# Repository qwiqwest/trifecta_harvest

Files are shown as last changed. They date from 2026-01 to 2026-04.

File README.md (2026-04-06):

# Smart Harvest

### Solar-Powered Edge Computer Vision System for Automated Fruit Ripeness Monitoring

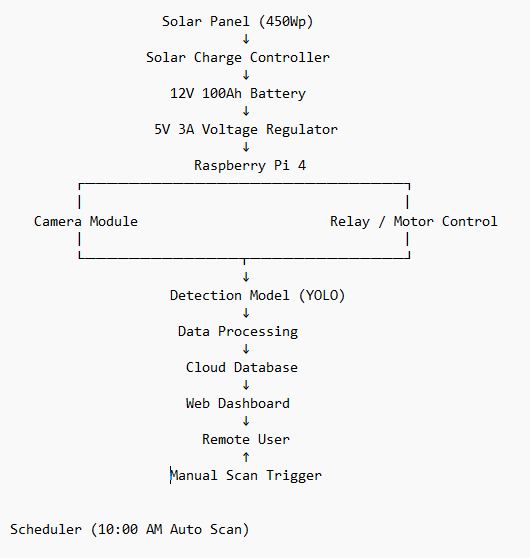
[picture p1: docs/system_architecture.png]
System Architecture


Smart Harvest is an embedded edge-AI system developed to support automated fruit ripeness monitoring in agricultural environments. The system integrates renewable energy, embedded computing, computer vision, and cloud-based monitoring to enable autonomous field operation.

The platform performs scheduled image acquisition and ripeness detection using a YOLO-based model deployed on a Raspberry Pi. Detection results are transmitted to a cloud database and visualized through a web-based monitoring dashboard, allowing remote observation and manual system triggering.

---

## System Architecture

The system consists of three main subsystems:

**Power System**

* 450 Wp solar panel
* Solar charge controller
* 12V 100Ah battery
* 5V 3A voltage regulator

**Edge Processing**

* Raspberry Pi 4 as the main controller
* Camera module for image acquisition
* YOLO-based ripeness detection model
* Custom relay PCB for motor control
* Automated daily scanning scheduler (10:00 AM)

**Cloud Monitoring**

* Cloud database for data storage
* Web-based IoT dashboard
* Remote user monitoring and manual scan triggering

---

## Key Capabilities

* Solar-powered autonomous operation
* Edge AI deployment for on-device fruit detection
* Integrated mechanical scanning mechanism
* Remote monitoring and control through web interface
* Full hardware–software system integration

---

## Demonstration

Live demonstration:
https://youtu.be/be947bb0I0M

Live system interface:
https://smartharvest.online
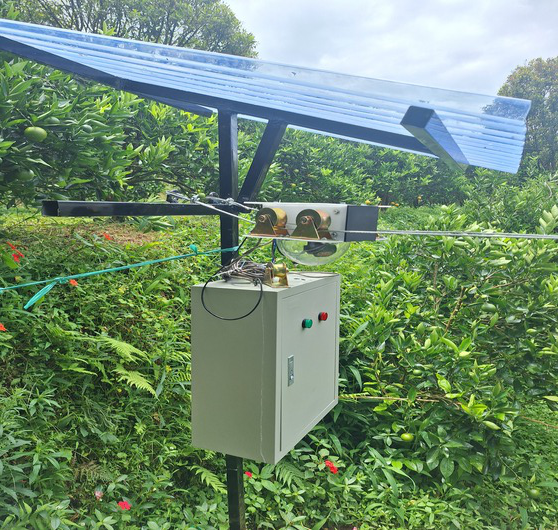
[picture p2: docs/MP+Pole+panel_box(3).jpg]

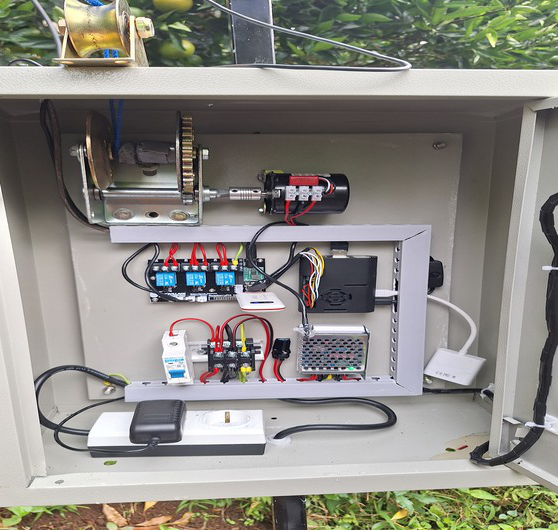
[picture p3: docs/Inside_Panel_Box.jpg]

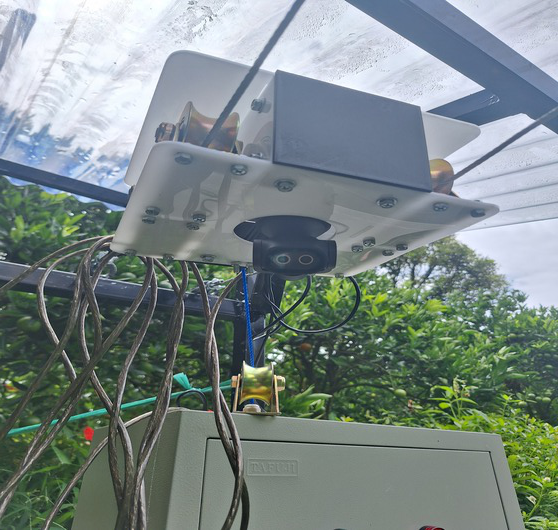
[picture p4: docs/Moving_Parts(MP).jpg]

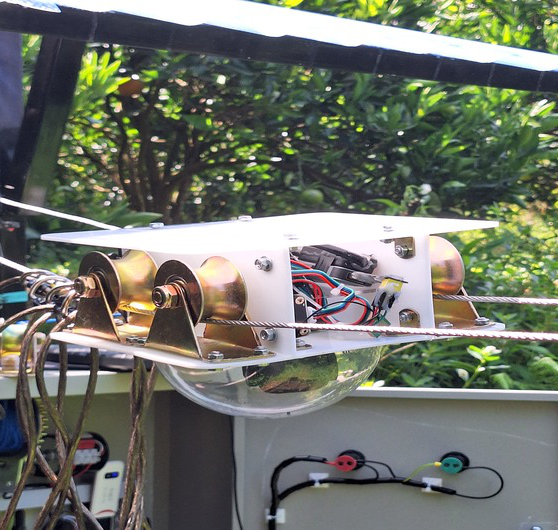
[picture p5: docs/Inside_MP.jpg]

---

## Repository Structure

* docs/ – system documentation and architecture diagram
* hardware/ – electrical design, PCB files, and wiring
* software/ – detection model, system control scripts, and dashboard code

---

## Technologies

Python • Raspberry Pi • YOLO • PCB Design • Solar Energy System • Web Dashboard • Cloud Database

---

## Future Research Direction

This project represents an initial step toward developing autonomous, solar-powered agricultural support systems.

Future work includes the development of a solar-powered automated organic waste composting system designed to convert agricultural waste into sustainable fertilizer through controlled mechanical processing and embedded control logic.

The focus will be on low-energy operation, system reliability, and sustainable off-grid deployment.

**Author**

Muhammad Rafli Abdillah
Undergraduate Student – Electrical Engineering
Research Interests: Embedded Systems, Computer Vision, Precision Agriculture

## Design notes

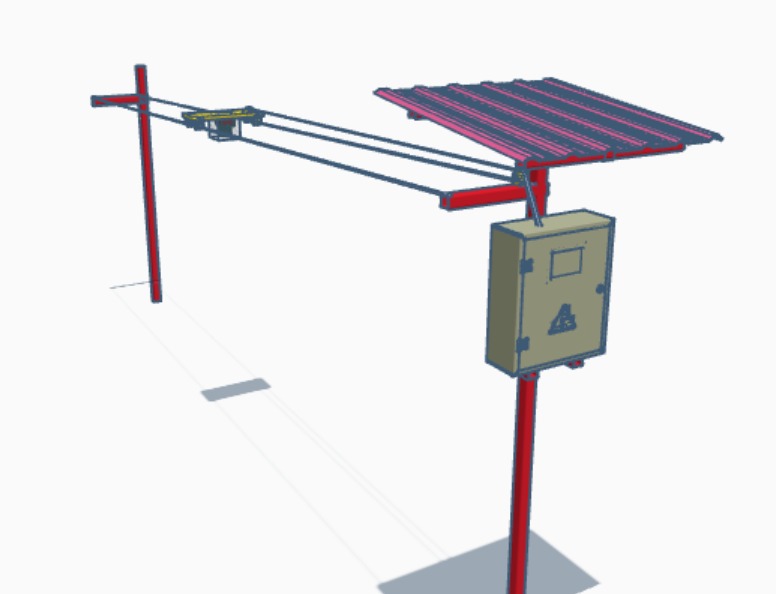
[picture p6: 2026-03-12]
hardware/mechanical/pole_design/mechanicalPole_desain_1.jpeg

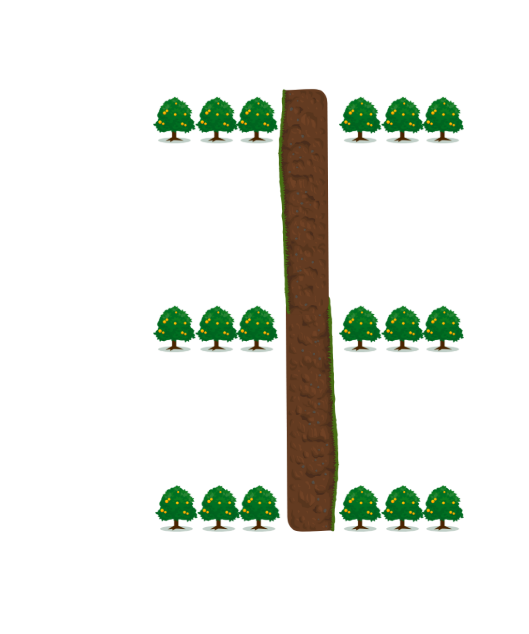
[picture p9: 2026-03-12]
software/dashboard/iot_dashboard/assets/img/peta5.png

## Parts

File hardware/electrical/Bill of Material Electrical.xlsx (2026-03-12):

No | Item |  | Qty
1 | Raspberry Pi 4 4GB |  | 1
2 | EMEET 4K PTZ |  | 1
3 | USB Extender |  | 1
4 | Pilot Lamp |  | 2
5 | AC 220V Motor |  | 1
6 | 4G Modem |  | 1
7 | MCB AC C2 |  | 1
8 | PSU Switching 12V 5A |  | 1
9 | Terminal 2 Stopkontak |  | 1
10 | Steker Arder Waterproof |  | 1
11 | Terminal Block Double DIN Rail |  | 3
12 | PSU Adapter Raspberry Pi 4 5V 3A USB Type C |  | 1
13 | Jack Power 12V |  | 2
14 | Relay Control Board | Relay 12V | 3
 |  | PC817 Optocoupler | 3
 |  | S8050 Transistor | 3
 |  | Stepdown MP1584 | 1
 |  | Dioda 1N4148 | 3
 |  | Resistor 220 | 6
 |  | Resistor 10k | 2
 |  | Konektor FP 40P | 1
 |  | Soket 12V PCB | 1
 |  | JST XH2.54 2P | 2
 |  | JST XH2.54 4P | 2
 |  | USB Socket | 2
 |  | Terminal Block 3P | 3

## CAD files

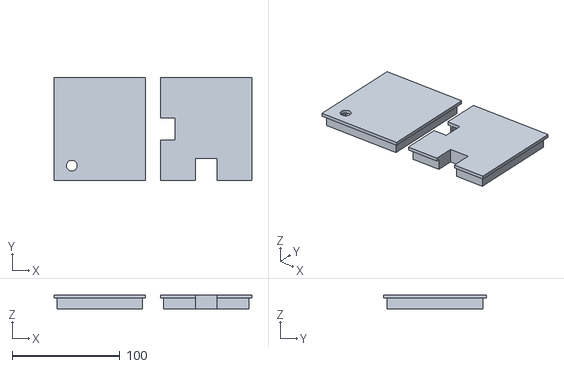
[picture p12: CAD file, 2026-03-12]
hardware/mechanical/moving_parts_design/penutupMovingPart.stl
183.5 x 95.0 x 13.0

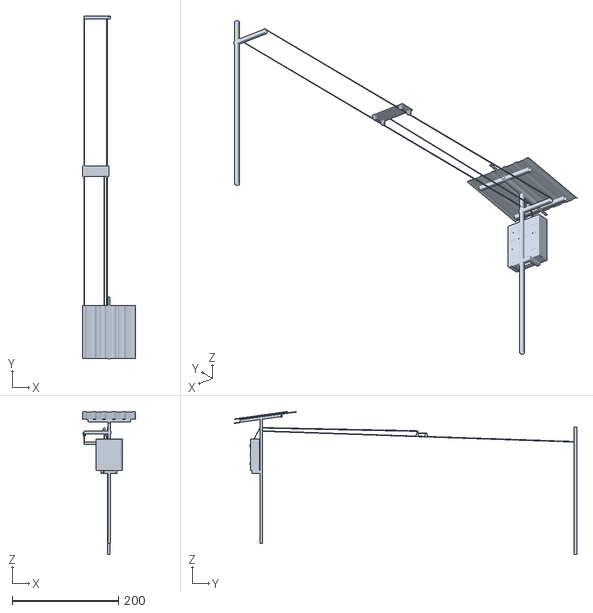
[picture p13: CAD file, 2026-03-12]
hardware/mechanical/pole_design/mechanicalPole_desain_1.stl
100.4 x 645.8 x 269.5

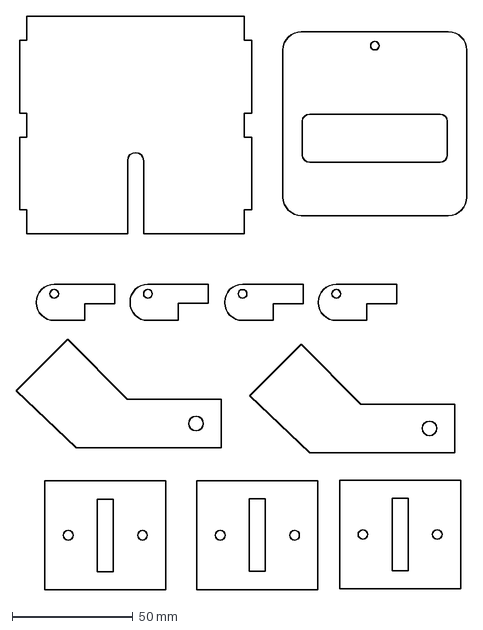
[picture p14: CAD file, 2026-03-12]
hardware/mechanical/moving_parts_design/middle.DXF
186.3 x 237.1 mm

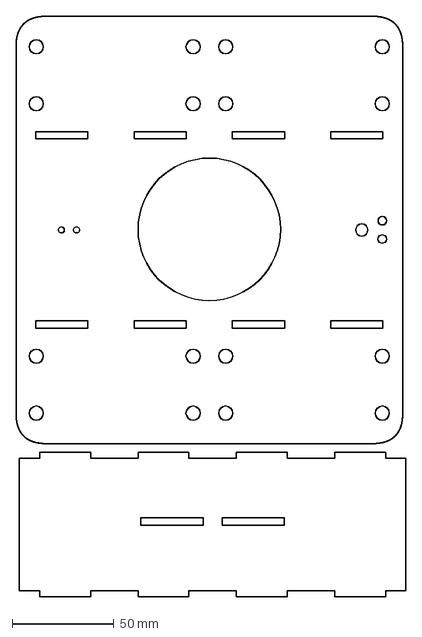
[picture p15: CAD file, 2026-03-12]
hardware/mechanical/moving_parts_design/bottom+left.DXF
191.6 x 285.2 mm

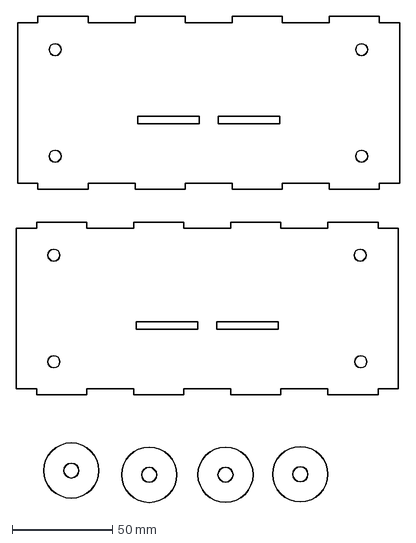
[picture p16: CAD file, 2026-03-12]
hardware/mechanical/moving_parts_design/rev1.DXF
190.7 x 241.9 mm

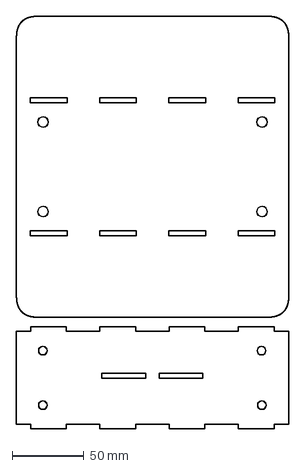
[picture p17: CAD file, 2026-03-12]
hardware/mechanical/moving_parts_design/top+right.DXF
190.2 x 287.8 mm

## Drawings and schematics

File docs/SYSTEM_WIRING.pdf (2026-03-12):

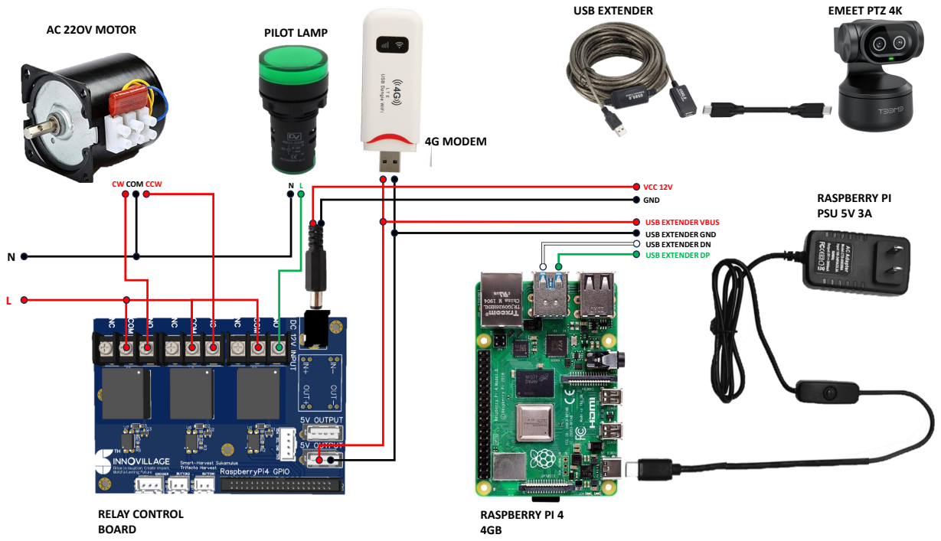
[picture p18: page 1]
CW COM CCW; VCC 12V GND; USB EXTENDER; EMEET PTZ 4K; AC 22OV MOTOR; PILOT LAMP; 4G MODEM; RASPBERRY PI 4 4GB; RELAY CONTROL BOARD; RASPBERRY PI PSU 5V 3A

USB EXTENDER VBUS
USB EXTENDER GND
USB EXTENDER DN
USB EXTENDER DP

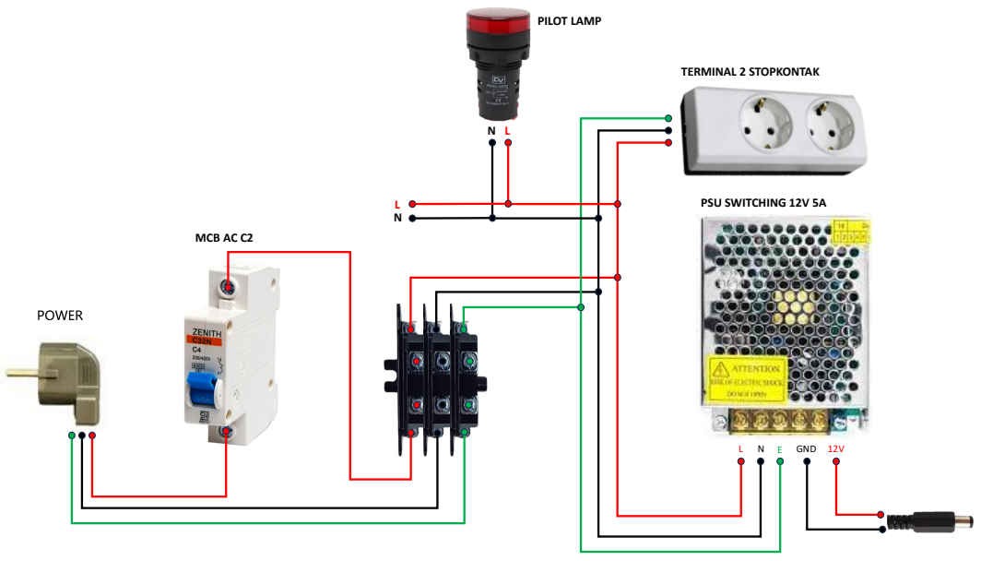
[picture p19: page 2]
GND 12V; MCB AC C2; PILOT LAMP; TERMINAL 2 STOPKONTAK; PSU SWITCHING 12V 5A

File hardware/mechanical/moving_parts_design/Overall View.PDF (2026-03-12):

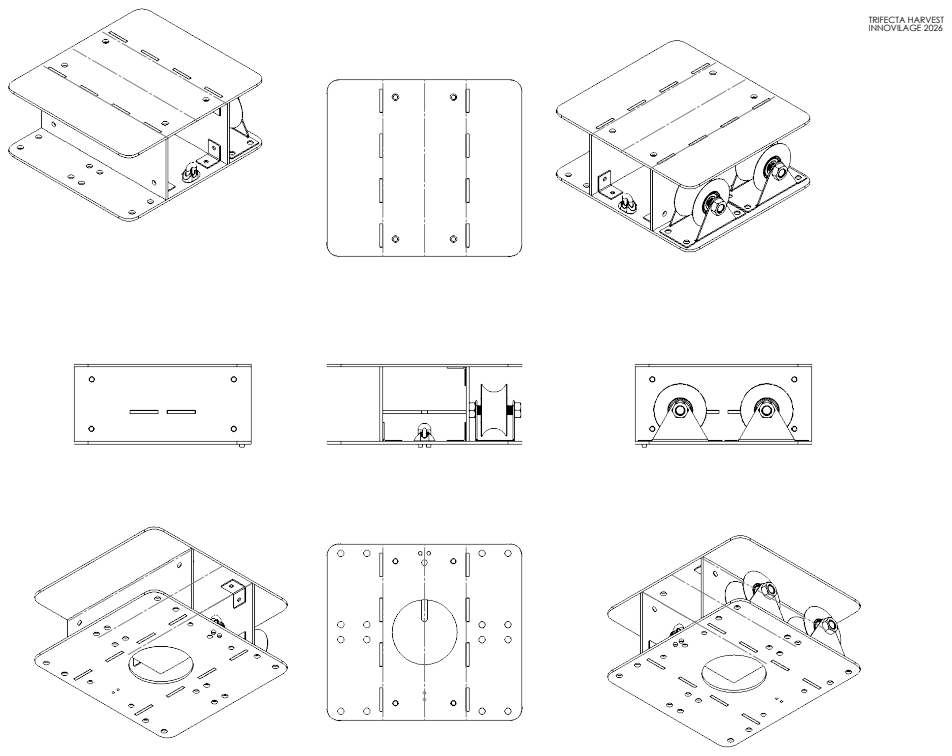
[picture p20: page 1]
TRIFECTA HARVEST INNOVILAGE 2026

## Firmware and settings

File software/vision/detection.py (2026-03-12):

import time
import requests
import subprocess
import RPi.GPIO as GPIO
from ultralytics import YOLO
import cv2


JUMLAH_BARIS = 2
MAX_RETRY = 1  # supaya tidak infinite loop

#Definisi pin
#17 -> lampu
#22 -> tarik
#27 -> ulur

MOTOR_GPIO_ACTIVE = True

# Gunakan penomoran BCM
GPIO.setmode(GPIO.BCM)

# Daftar pin
pinLampu = 17
pinTarik = 22
pinUlur = 27
pinMagnet = 26
pinStopper = 20
pins = [pinLampu, pinTarik, pinUlur, pinMagnet, pinStopper]

a1 = 0
a2 = 0
b1 = 0
b2 = 0

payload = {
    "a1":a1,
    "a2":a2,
    "b1":b1,
    "b2":b2
}

url = "https://smartharvest.online/assets/php/api_insert.php"

model = YOLO(r"/home/ubuntu2025/Desktop/yolov8/best.pt")

headers = {
    "User-Agent": "Mozilla/5.0",
    "Accept": "*/*"
}

#===FUNCTION===
def deteksi_jeruk(path, filename):
    result = model(path +filename +".jpg")
    result[0].save(filename= path + filename +"_dtc.jpg")
    jumlah_matang = 0
    jumlah_mentah = 0

    for box in result[0].boxes:
        cid = int(box.cls)

        if cid == 0:
            jumlah_matang += 1
        elif cid == 1:
            jumlah_mentah += 1

    return jumlah_mentah, jumlah_matang

def kirim_ke_database():
    payload = {
        "a1":a1,
        "a2":a2,
        "b1":b1,
        "b2":b2
    }
    print(payload)
    r = requests.post(
    url,
    data=payload,
    headers=headers,
    timeout=15,
    allow_redirects=True
    )
    print(r.status_code)
    print(r.text)
    
def bacaStopper():
    state = GPIO.input(pinStopper)
    print(state)
    return state

def setupGPIO():
    GPIO.setmode(GPIO.BCM)
    GPIO.setup(pins, GPIO.OUT)
    GPIO.setup(pinLampu, GPIO.OUT)
    GPIO.setup(pinMagnet, GPIO.IN)
    GPIO.setup(pinStopper, GPIO.IN)

def tarik(onDelay):
    
    GPIO.output(pinLampu, GPIO.HIGH)
    GPIO.output(pinTarik, GPIO.HIGH)
    print("tarik on")
    time.sleep(onDelay)
                
    GPIO.output(pinTarik, GPIO.LOW)
    print("tarik off")
    
    GPIO.output(pinLampu, GPIO.LOW)
            
        
    
def ulur(onDelay, offDelay):
    GPIO.output(pinLampu, GPIO.HIGH)
    if MOTOR_GPIO_ACTIVE:
        GPIO.output(pinUlur, GPIO.HIGH)
        print("ulur on")
    time.sleep(onDelay)
    
    if MOTOR_GPIO_ACTIVE:
        GPIO.output(pinUlur, GPIO.LOW)
        print("ulur off")
    time.sleep(offDelay)
    GPIO.output(pinLampu, GPIO.LOW)
    

def rotateCamera(orientasi):
    #pan_absolute 0x009a0908 (int)      : min=-540000 max=540000 step=3600 default=0 value=0
    #tilt_absolute 0x009a0909 (int)     : min=-324000 max=324000 step=3600 default=0 value=0
    #kiri   :
    #v4l2-ctl --set-ctrl=pan_absolute=-380000
    #v4l2-ctl --set-ctrl=tilt_absolute=50000
    #tengah :
    #v4l2-ctl --set-ctrl=pan_absolute=-80000
    #v4l2-ctl --set-ctrl=tilt_absolute=50000
    if orientasi == "KIRI":
        subprocess.run(["v4l2-ctl", "-d", "/dev/video0", "--set-ctrl=pan_absolute=-324000"])
        subprocess.run(["v4l2-ctl", "-d", "/dev/video0", "--set-ctrl=tilt_absolute=36000"])
    elif orientasi == "KANAN": 
        subprocess.run(["v4l2-ctl", "-d", "/dev/video0", "--set-ctrl=pan_absolute=324000"])
        subprocess.run(["v4l2-ctl", "-d", "/dev/video0", "--set-ctrl=tilt_absolute=36000"])
    elif orientasi == "HOME":
        subprocess.run(["v4l2-ctl", "-d", "/dev/video0", "--set-ctrl=pan_absolute=0"])
        subprocess.run(["v4l2-ctl", "-d", "/dev/video0", "--set-ctrl=tilt_absolute=-270000"])
    elif orientasi == "DEFAULT":
        subprocess.run(["v4l2-ctl", "-d", "/dev/video0", "--set-ctrl=pan_absolute=0"])
        subprocess.run(["v4l2-ctl", "-d", "/dev/video0", "--set-ctrl=tilt_absolute=0"])

def capture_image(path, filenameSave):
    cap = cv2.VideoCapture("/dev/video0", cv2.CAP_V4L2)

    cap.set(cv2.CAP_PROP_FOURCC, cv2.VideoWriter_fourcc(*'MJPG'))
    cap.set(cv2.CAP_PROP_FPS, 15)
    cap.set(cv2.CAP_PROP_FRAME_WIDTH, 3840)
    cap.set(cv2.CAP_PROP_FRAME_HEIGHT, 2160)
    
    for _ in range(120):
        ret, frame = cap.read()
    ret, frame = cap.read()

    if ret:
        frame = cv2.flip(frame, 0)
        cv2.imwrite(path + filenameSave +".jpg", frame)
        print("Gambar tersimpan dengan shape:", frame.shape)
    else:
        print("Gagal membaca kamera!")

    cap.release()



def proses_deteksi(path, baris, sisi, filenameSave):
    global a1, a2, b1, b2
    retry = 0
    mentah = 0
    matang = 0

    # while mentah == 0 and matang == 0:
    #     print("Ambil gambar ulang...")
    capture_image(path, filenameSave)

    mentah, matang = deteksi_jeruk(path, filenameSave)

    print("Mentah:", mentah)
    print("Matang:", matang)

        # retry += 1
        # if retry >= MAX_RETRY:
        #     print("Gagal deteksi setelah beberapa percobaan")
        #     break
    
    totalBuah = matang + mentah
    
    if sisi == "KIRI":
        if baris == 1:
            a1 = matang
            print(f"a1={a1}")
        elif baris == 2:
            a2 = matang
            print(f"a2={a2}")
    elif sisi == "KANAN":
        if baris == 1:
            b1 = matang
            print(f"b1={b1}")
        elif baris == 2:
            b2 = matang
            print(f"b2={b2}")
    
    
    # if sisi == "KIRI":
    #     payload[f"baris{baris}"]["A"]["persentase"] = persentase
    # if sisi == "KANAN":
    #     payload[f"baris{baris}"]["B"]["persentase"] = persentase
    
    return mentah, matang

# ===============================
# MAIN SETUP
# ===============================
if __name__ == "__main__":
        
    path = "/home/ubuntu2025/Desktop/yolov8/img_out/"       
    filename = time.strftime("foto_%Y%m%d_%H%M%S")
    
    setupGPIO()
    rotateCamera("DEFAULT")
    time.sleep(2)
    rotateCamera("HOME")
    time.sleep(2)
    #tarik(5)
    # ===============================
    # MAIN LOOP
    # ===============================

    for baris in range(1, JUMLAH_BARIS+1):
        print(f"Mulai baris {baris}")

        # Geser/ulur mekanik
        if baris == 1:
            rotateCamera("DEFAULT")
            time.sleep(2)
            rotateCamera("HOME")
            ulur(22, 1)
        elif baris == 2:
            rotateCamera("DEFAULT")
            time.sleep(2)
            rotateCamera("HOME")
            ulur(110, 1)#30,1

        # ======================
        # ROTASI KIRI
        # ======================
        rotateCamera("DEFAULT")
        time.sleep(2)
        rotateCamera("KIRI")
        filenameKiri = filename + f"baris{baris}_kiri"
        proses_deteksi(path, baris, "KIRI", filenameKiri)
        
        # ======================
        # ROTASI KANAN
        # ======================
        rotateCamera("DEFAULT")
        time.sleep(2)
        rotateCamera("KANAN")
        filenameKanan = filename + f"baris{baris}_kanan"
        proses_deteksi(path, baris, "KANAN", filenameKanan)
        


    # ===============================
    # Kembali ke HOME
    # ===============================
    kirim_ke_database()
    rotateCamera("DEFAULT")
    time.sleep(2)
    rotateCamera("HOME")
    tarik(137)
    rotateCamera("DEFAULT")
    time.sleep(2)
    rotateCamera("HOME")
    print("Selesai semua baris")

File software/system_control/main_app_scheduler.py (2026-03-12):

from apscheduler.schedulers.background import BackgroundScheduler
import subprocess
import datetime
import threading
import requests
import time
import deteksi

# ========================
# CONFIG WEB COMMAND
# ========================
URL_GET = "https://smartharvest.online/assets/php/get_command.php"
URL_DONE = "https://smartharvest.online/assets/php/done_command.php"

headers = {
    "User-Agent": "Mozilla/5.0",
    "Accept": "*/*"
}

scheduler = BackgroundScheduler()
deteksi_lock = threading.Lock()


# ========================
# FUNGSI KAMERA
# ========================
def set_kamera_home():
    deteksi.rotateCamera("DEFAULT")
    time.sleep(2)
    deteksi.rotateCamera("HOME")
    deteksi.setupGPIO()
    #if deteksi.bacaStopper():
     #   deteksi.tarik(10, 1)


# ========================
# FUNGSI DETEKSI
# ========================
def jalankan_deteksi():
    if deteksi_lock.locked():
        print("Deteksi masih berjalan, skip...")
        return

    with deteksi_lock:
        print("Deteksi dijalankan:", datetime.datetime.now())

        # Gunakan run supaya blocking dan lock benar-benar efektif
        subprocess.run(
            ["/home/ubuntu2025/Desktop/yolov8/venv3.10/bin/python", "/home/ubuntu2025/Desktop/yolov8/source_code/deteksi.py"]
        )

        print("Deteksi selesai")


# ========================
# POLLING WEB MANUAL COMMAND
# ========================
def polling_web_command():
    while True:
        try:
            r = requests.get(URL_GET, headers=headers, timeout=10).json()

            if r.get("command"):
                print("COMMAND dari web:", r)

                if r["command"] == "scan":
                    requests.post(
                        URL_DONE,
                        data={"id": r["id"]},
                        headers=headers,
                        timeout=10
                    )
                    jalankan_deteksi()

                

        except Exception as e:
            print("Error polling:", e)

        time.sleep(10)


# ========================
# INIT SISTEM
# ========================
print("Set kamera ke HOME")
set_kamera_home()

print("Start scheduler 10:00")

# Jadwal otomatis (ubah sesuai kebutuhan)
#scheduler.add_job(jalankan_deteksi, 'interval', minutes=30)
scheduler.add_job(jalankan_deteksi, 'cron', hour=10, minute=00)
scheduler.start()

# Start polling thread
threading.Thread(target=polling_web_command, daemon=True).start()

print("Sistem berjalan 10:00...")

# Loop utama agar program tidak exit
while True:
    time.sleep(60)

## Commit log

2026-02-12 Update Pemabahruan Heatmap
2026-03-13 Documentation (Device)
